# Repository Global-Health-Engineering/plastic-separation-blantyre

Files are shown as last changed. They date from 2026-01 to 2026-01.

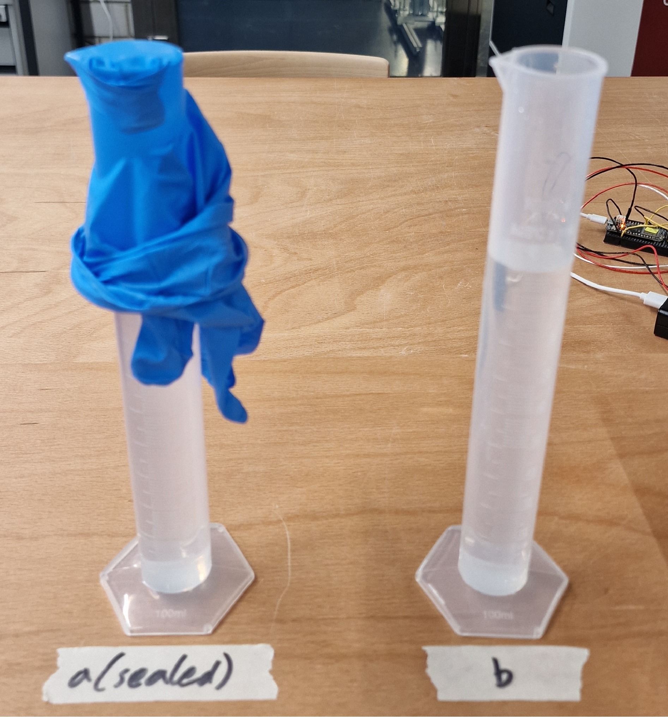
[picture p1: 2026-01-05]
media/testing/04-light_sink_float_sep-proof_of_concept/evaporation_test2.jpg

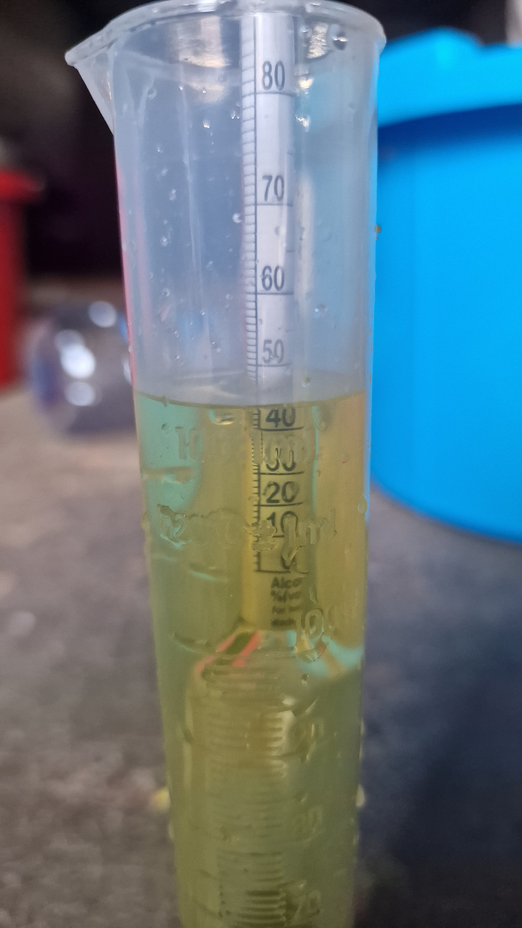
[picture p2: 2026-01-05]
media/testing/07-sink_float_prototype_test/ethanol_water_measurement-post_separation.jpg

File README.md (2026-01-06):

<!-- badges: start -->


<!-- badges: end -->

<h1> Plastic Separator - Design and Results </h1>

<b>Contributors</b>  
- Sven Prinz <a href="https://orcid.org/0009-0000-4485-1235">
ORCID logo 0009-0000-4485-1235
</a>, <a href="sprinz@ethz.ch">sprinz@ethz.ch</a> *author, maintainer*  
- Jakub Tkaczuk <a href="https://orcid.org/0000-0001-7997-9423">
ORCID logo 0000-0001-7997-9423
</a> *supervisor*  
- Elizabeth Tilley <a href="https://orcid.org/0000-0002-2095-9724">
ORCID logo 0000-0002-2095-9724
</a> *supervisor*  

<br>
<p align="middle"> 

<br><br>
It compliments the openly-accessible master’s thesis, available on the<br \>  
<a href="http://hdl.handle.net/20.500.11850/791439">ETH Research Collection</a>.
</p>

<b>Date of Thesis</b>  
- 2025-05-28 until 2025-12-19

<b>Locations</b>  
- Zurich, Switzerland
- Blantyre, Malawi

# Thesis Abstract

The growing thread of plastic waste is visible all over the world. Production and consumption increase each year, while the rate of recycling lags behind significantly, heightening the burden on health and the environment.
Efforts are being made to counteract this development, with mixed outcomes.
In collaboration with *ArtMal* and *WASTE Advisers*, two NGOs active in Blantyre, Malawi, it is aimed to return discarded plastic waste to the recycling process.
After failed attempts to reuse the plastic in form of molded bricks due to property differences between various types, a large quantity of mixed plastic flakes remains.
The goal of this thesis is to divide the mixed flakes by their type and, thus, reintroduce them into the ongoing recycling efforts in Malawi.

The thesis is structured in two parts.
During the first period, a literature review including small scale testing was conducted to evaluate the feasibility of various plastic separation methods.
The following field work in Malawi consisted of the plastic waste assessment, the design and manufacturing of a suitable separation prototype, and the validation of its functionality.

It was found that the most promising method for the setting in Blantyre is the sink-float method due to its simplicity and robustness.
The resulting prototype is a manually operated two-stage sink-float separator which addresses the sorting of PP, HDPE, and PET.
Due to its fabrication out of locally available material, a cost-efficient and reproducible design was obtained.
With this prototype, separation purities of 96.55 % for PET and 99.77 % for HDPE were achieved, allowing their reuse in recycling operations by *ArtMal* and *WASTE Advisers*. The purity of PP remained insufficient at 69.76 %.

However, the resulting recyclates are not of satisfying quality for all uses due to a mix of colors as well as a small amounts of PVC and other contaminants remaining in the product.
Especially for contaminated flakes, a supplementary washing solution is necessary.
Additionally, one aspect that this prototype has in common with other separation methods is the need for affordable (in-line) quality verification of the recyclate.
By addressing these complementary systems such as the washing, contaminant removal, and quality control in future work, the prototype's deployment beyond the flakes stored by *WASTE Advisers* becomes viable.

# Repository Overview

To supplement the thesis and allow reproduction of the prototype design and results, all developed resources are published in this repository.
The repository has the following directory tree:

    .
    ├── analysis
    ├── data
    │   ├── derived_data
    │   └── raw_data
    ├── hardware
    │   ├── design
    |   |   ├── S_separation
    |   |   |   └── vacuum_mellerware
    |   |   └── W_washing
    │   └── testing
    └── media
        ├── design
        ├── manufacturing
        └── testing
            ├── 01-sink_float_sep-proof_of_concept
            ├── 02-hdp_sep-proof_of_concept
            ├── 03-ldp_sep-proof_of_concept
            ├── 04-light_sink_float_sep-proof_of_concept
            ├── 05-water_quality_test
            ├── 06-plastic_waste_analysis
            └── 07-sink_float_prototype_test
Each main directory contains its own `README.md` file describing the content in more detail.

| Main directory | Content |
|---|---|
| `./analysis` | Code for data analysis |
| `./data` | Data generated during the project |
| `./hardware` | Prototype design, and testing documentation |
| `./media` | Photos and videos concerning the project |

# License

The complete design and available materials are licensed under [Creative Commons Attribution 4.0 International](https://github.com/Global-Health-Engineering/plastic-separation-blantyre/blob/main/LICENSE.md).

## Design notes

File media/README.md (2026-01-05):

---
README for `./media`
---

In the `./media` directory, photos and videos concerning the project are stored.
It is divided into three sub-directories: `design`, `manufacturing`, and `testing`.

**Note:** Not all media files (especially videos) are available on GitHub. Request access to supplementary material from the author.

# `media/design`

This directory contains screenshots of the prototype unit representations in the CAD software Siemens NX 1988.
The underlying part files are available in the `./hardware/design` directory.

Furthermore, the projected workflow of the washing and separation process is visualized in a video.

# `media/manufacturing`

Here, the fabrication process and milestones of the prototype manufacturing are documented.

# `media/testing`

In this directory, the media recorded during the tests is provided.
It is sorted into one folder for each conducted test and named correspondingly.
For detailed information on the different tests, see the `README.md` file in the `./hardware/testing` directory.

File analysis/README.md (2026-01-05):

---
README for `./analysis`
---

This folder contains the R script `separation_result_derivation.R` to extract, clean, and format the test results acquired from RTT's flakeanalyser.
It reads the excel sheet obtained from the flakeanalyser for each measured sample `07-sink_float_prototype_test-sample_X.xlsx` (with X = 1...5) in the directory `./analysis/data/raw_data`. After the processing, each result (two files per sample) is saved to `./analysis/data/derived_data` named `07-sink_float_prototype_test-sample_X-separation.csv` and `07-sink_float_prototype_test-sample_X-grain_size.csv` as CSV files.

| Input | Directory |
| --- | --- |
| `07-sink_float_prototype_test-sample_1.xlsx` | `./analysis/data/raw_data` |
| `07-sink_float_prototype_test-sample_2.xlsx` | `./analysis/data/raw_data` |
| `07-sink_float_prototype_test-sample_3.xlsx` | `./analysis/data/raw_data` |
| `07-sink_float_prototype_test-sample_4.xlsx` | `./analysis/data/raw_data` |
| `07-sink_float_prototype_test-sample_5.xlsx` | `./analysis/data/raw_data` |

| Output | Directory |
| --- | --- |
| `07-sink_float_prototype_test-sample_1-separation.csv` | `./analysis/data/derived_data` |
| `07-sink_float_prototype_test-sample_1-grain_size.csv` | `./analysis/data/derived_data` |
| `07-sink_float_prototype_test-sample_2-separation.csv` | `./analysis/data/derived_data` |
| `07-sink_float_prototype_test-sample_2-grain_size.csv` | `./analysis/data/derived_data` |
| `07-sink_float_prototype_test-sample_3-separation.csv` | `./analysis/data/derived_data` |
| `07-sink_float_prototype_test-sample_3-grain_size.csv` | `./analysis/data/derived_data` |
| `07-sink_float_prototype_test-sample_4-separation.csv` | `./analysis/data/derived_data` |
| `07-sink_float_prototype_test-sample_4-grain_size.csv` | `./analysis/data/derived_data` |
| `07-sink_float_prototype_test-sample_5-separation.csv` | `./analysis/data/derived_data` |
| `07-sink_float_prototype_test-sample_5-grain_size.csv` | `./analysis/data/derived_data` |

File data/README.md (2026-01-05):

---
README for `./data`
---

The `./data` directory contains two sub-directories: `raw_data` and `derived_data`.

# `data/raw_data`

This directory contains unedited raw data. The data was obtained from tests conducted during the course of the master thesis.
The procedures with which the results were obtained are documented for each test in the testing documents in the`./hardware/testing` directory.

Files are stored in Microsoft excel worksheets (xlsx) files.

| Filename | Date of data collection | Geographic location of data collection |
| --- | --- | --- |
| `01_sink_float_sep-proof_of_concept-results.xlsx` | 2025-06-15 | ETH CLA, Tannenstrasse 3, 8092 Zurich, Switzerland |
| `02-hdp_sep-proof_of_concept-results.xlsx` | 2025-06-18 | ETH CLA, Tannenstrasse 3, 8092 Zurich, Switzerland |
| `03-ldp_sep-proof_of_concept-results.xlsx` | 2025-06-19 | ETH CLA, Tannenstrasse 3, 8092 Zurich, Switzerland |
| `04-light_sink_float_sep-proof_of_concept-results.xlsx` | 2025-07-04 - 2025-07-07 | ETH CLA, Tannenstrasse 3, 8092 Zurich, Switzerland |
| `07-sink_float_prototype_test-sample_1.xlsx` | 2025-09-24 (Sampling) | WASTE Advisers Innovation Hub, Chigumula, Malawi (15°53'08.5"S 35°03'49.5"E) |
| `07-sink_float_prototype_test-sample_2.xlsx` | 2025-09-24 (Sampling) | WASTE Advisers Innovation Hub, Chigumula, Malawi (15°53'08.5"S 35°03'49.5"E) |
| `07-sink_float_prototype_test-sample_3.xlsx` | 2025-09-24 (Sampling) | WASTE Advisers Innovation Hub, Chigumula, Malawi (15°53'08.5"S 35°03'49.5"E) |
| `07-sink_float_prototype_test-sample_4.xlsx` | 2025-09-24 (Sampling) | WASTE Advisers Innovation Hub, Chigumula, Malawi (15°53'08.5"S 35°03'49.5"E) |
| `07-sink_float_prototype_test-sample_4.xlsx` | 2025-09-24 (Sampling) | WASTE Advisers Innovation Hub, Chigumula, Malawi (15°53'08.5"S 35°03'49.5"E) |

For further information see the `README.md` file in the `./data/raw_data` directory.

# `data/derived_data`

This directory contains data that has been cleaned, processed, and formatted using the data in the `./data/raw_data` directory.
Files, where only trivial analysis steps were applied, are stored in xlsx format with the calculations implemented in the worksheet.
For the cases, where a (little) more comprehensive processing was needed, the files are stored in comma-separated values (CSV) files.

For further information see the `README.md` file in the `./data/derived_data` directory.

# File list

| directory | filename | description |
| --- | --- | --- |
| `./data/raw_data` | `01_sink_float_sep-proof_of_concept-results.xlsx` | Raw result data recorded during test 01 "Sink-float separation - Proof of concept" |
| `./data/raw_data` | `02-hdp_sep-proof_of_concept-results.xlsx` | Raw result data recorded during test 02 "HDP separation - Proof of concept" |
| `./data/raw_data` | `03-ldp_sep-proof_of_concept-results.xlsx` | Raw result data recorded during test 03 "LDP separation - Proof of concept" |
| `./data/raw_data` | `04-light_sink_float_sep-proof_of_concept-results.xlsx` | Raw result data recorded during test 04 "Light sink-float separation - Proof of concept" |
| `./data/raw_data` | `07-sink_float_prototype_test-sample_1.xlsx` | Raw result data of sample 1 from the prototype tests analyzed by the flakeanalyser from RTT |
| `./data/raw_data` | `07-sink_float_prototype_test-sample_2.xlsx` | Raw result data of sample 2 from the prototype tests analyzed by the flakeanalyser from RTT |
| `./data/raw_data` | `07-sink_float_prototype_test-sample_3.xlsx` | Raw result data of sample 3 from the prototype tests analyzed by the flakeanalyser from RTT |
| `./data/raw_data` | `07-sink_float_prototype_test-sample_4.xlsx` | Raw result data of sample 4 from the prototype tests analyzed by the flakeanalyser from RTT |
| `./data/raw_data` | `07-sink_float_prototype_test-sample_4.xlsx` | Raw result data of sample 5 from the prototype tests analyzed by the flakeanalyser from RTT |
| `./data/raw_data` | `README.md` | Information regarding the files in the directory including a description of parameters used |
| `./data/derived_data` | `01_sink_float_sep-proof_of_concept-evaluations.xlsx` | Processed result data of test 01 "Sink-float separation - Proof of concept" |
| `./data/derived_data` | `02-hdp_sep-proof_of_concept-evaluations.xlsx` | Processed result data of test 02 "HDP separation - Proof of concept" |
| `./data/derived_data` | `03-ldp_sep-proof_of_concept-evaluations.xlsx` | Processed result data of test 03 "LDP separation - Proof of concept" |
| `./data/derived_data` | `04-light_sink_float_sep-proof_of_concept-evaluations.xlsx` | Processed result data of test 04 "Light sink-float separation - Proof of concept" |
| `./data/derived_data` | `07-sink_float_prototype_test-sample_1-grain_size.csv` | Processed material composition results of sample 1 from the prototype tests analyzed by the flakeanalyser from RTT |
| `./data/derived_data` | `07-sink_float_prototype_test-sample_1-separation.csv` | Processed grain size composition results of sample 1 from the prototype tests analyzed by the flakeanalyser from RTT |
| `./data/derived_data` | `07-sink_float_prototype_test-sample_2-grain_size.csv` | Processed material composition results of sample 2 from the prototype tests analyzed by the flakeanalyser from RTT |
| `./data/derived_data` | `07-sink_float_prototype_test-sample_2-separation.csv` | Processed grain size composition results of sample 2 from the prototype tests analyzed by the flakeanalyser from RTT |
| `./data/derived_data` | `07-sink_float_prototype_test-sample_3-grain_size.csv` | Processed material composition results of sample 3 from the prototype tests analyzed by the flakeanalyser from RTT |
| `./data/derived_data` | `07-sink_float_prototype_test-sample_3-separation.csv` | Processed grain size composition results of sample 3 from the prototype tests analyzed by the flakeanalyser from RTT |
| `./data/derived_data` | `07-sink_float_prototype_test-sample_4-grain_size.csv` | Processed material composition results of sample 4 from the prototype tests analyzed by the flakeanalyser from RTT |
| `./data/derived_data` | `07-sink_float_prototype_test-sample_4-separation.csv` | Processed grain size composition results of sample 4 from the prototype tests analyzed by the flakeanalyser from RTT |
| `./data/derived_data` | `07-sink_float_prototype_test-sample_5-grain_size.csv` | Processed material composition results of sample 5 from the prototype tests analyzed by the flakeanalyser from RTT |
| `./data/derived_data` | `07-sink_float_prototype_test-sample_5-separation.csv` | Processed grain size composition results of sample 5 from the prototype tests analyzed by the flakeanalyser from RTT |
| `./data/derived_data` | `README.md` | Information regarding the files in the directory including a description of parameters used |

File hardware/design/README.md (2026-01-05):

---
README for `./hardware/design`
---

This directory contains the design files for the developed prototype.
The parts were designed using the CAD software **NX 1988** from Siemens.

The higher level assembly of the design `A_full_process_line.prt` consists of the two prototype units designed in the course of this thesis - the air classifier and the sink-float separator - and the washing drum built by *Laios (2025)*.
The folder `S_separation` contains both assembly files and their subordinate part files (provided as PRT and STP files), as well as the technical drawings of the parts (provided as PRT and PDF files) of the two separation prototype units.
Additionally, the folder `vacuum_mellerware` in the `./hardware/design/S_separation` directory contains pictures in PNG format that represent the vacuum cleaner used in the assembly of the air classifier design.
The vacuum cleaner depicted in the figures is the <a href="http://www.mellerware.co.za/products/mellerware-vacuum-cleaner-bagless-cyclone-plastic-red-1.2l-1200w-innovac/31120A">Bagless Cyclone Vacuum Cleaner "Innovac"</a> by Mellerware.
The directory `./hardware/design/W_washing` contains a digital version of *Laois*' washing drum prototype for representation purposes. Its assembly is only available as  Siemens PRT file, while the individual parts are also available as STP files.

Apart from the CAD files, `HDPE_sheet_utilization.pdf` in `./hardware/design` offers the area utilization of the HDPE sheets used during production of the prototype. The initial HDPE sheets were manufactured by ArtMal in Blantyre, Malawi.

**Reference:**
*Laios, T. (2025). Plastic for Recycling Cleaning [Unpublished master thesis]. ETH Zurich.*

# Used naming and color coventions

**File naming convention**

Each designed prototype part file (and its corresponding drawing files) follow the same naming scheme: P_UU_T_NN_PARTNAME.FILEEXTENSION

| Placeholder | Description | Possible values |
| --- | --- | --- |
| P | Abbreviation of process | W (washing), S (separation) |
| UU | Abbreviation of prototype unit | AC (Air classifier), SF (Sink-float separator), WS (Washer drum) |
| T | Abbreviation of NX file type | A (Assembly), M (Model) |
| NN | Identification number of part (unique within a prototype unit) | Natural number incrementing in order of file creation |
| PARTNAME | Name of part/assembly | Any character allowed in file names |
| FILEEXTENSION | Extension of file type | prt (Siemens NX part file/drawing file), stp (step file), pdf (technical drawing exported as PDF) |

**Color codes used in Siemens NX 1988:**
| Material | Color | Translucency setting |
| --- | --- | --- |
| HDPE sheets | Ash Gray | 0% |
| Perforated steel sheets | Granite Gray | 50% |
| PVC pipe | Medium Khaki | 0% |
| Rubber seals | Dark Gray | 0% |
| Steel frame/sheets | Medium Steel | 0% |
| Tubes | Deep Stone | 0% |
| Wood | Medium Umber | 0% |

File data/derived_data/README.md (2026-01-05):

---
README for `./data/derived_data`
---

This folder contains derived data obtained from the tests. The raw data is located in the directory `./data/raw_data`.

The first four evaluation files are obtained from small-scale proof-of-concept tests conducted in the lab:
- `01_sink_float_sep-proof_of_concept-evaluations.xlsx`
- `02-hdp_sep-proof_of_concept-evaluations.xlsx`
- `03-ldp_sep-proof_of_concept-evaluations.xlsx`
- `04-light_sink_float_sep-proof_of_concept-evaluations.xlsx`

As the calculations are trivial, they are directly performed in the excel sheet using the following formulas:
- purity_float = mass(float right) / mass(float total)
- purity_sink = mass(sink right) / mass(sink total)
- combined_purity = 0.5*(purity_float + purity_sink)

These evaluation sheets have an individual structure due to varying tested parameters. Thus, the specific data dictionary is presented in the "general_info" sheet of each file.

The five files `07-sink_float_prototype_test-sample_X-separation.csv` and the five files `07-sink_float_prototype_test-sample_X-grain_size.csv` (with X = 1...5) are generated using the `separation_result_derivation.R` script in the `./analysis` directory. For further information on the processing, see the `README.md` and the R script in the `./analysis` directory.
The results' structure is identical and the data dictionary for the two file classes are explained here:

**Data dictionary - 'separation' files:**
| Variable | Description | Unit |
| --- | --- | --- |
| material | Different material types of analysis | - |
| mass_percent | Mass fraction of that material in the sample | % |
| volume_percent | Volume fraction of that material in the sample | % |
| object_count | Absolute number of detected flakes for that material | - |

**Data dictionary - 'grain_size' files:**
| Variable | Description | Unit |
| --- | --- | --- |
| gain_size | Grain size ranges returned by flakeanalyser | mm |
| area_mm2 | Area fraction of that material in the sample | mm^2 |
| area_percent | Volume fraction of that material in the sample | % |

For more information see the `README.md` file in the `./data` directory.

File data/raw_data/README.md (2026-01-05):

---
README for `./data/raw_data`
---

This folder contains raw data obtained from the tests.

The first four result files are obtained from small-scale proof-of-concept tests conducted in the lab:
- `01_sink_float_sep-proof_of_concept-results.xlsx`
- `02-hdp_sep-proof_of_concept-results.xlsx`
- `03-ldp_sep-proof_of_concept-results.xlsx`
- `04-light_sink_float_sep-proof_of_concept-results.xlsx`

They have an individual structure due to varying tested parameters. Thus, the specific data dictionary is presented in the "general_info" sheet of each file.

The five files `07-sink_float_prototype_test-sample_X.xlsx` (with X = 1...5) are the results of the flakeanalyser from RTT which was used to determine the composition of the prototype samples. Their structure is identical and the most important parameters on the first sheet are explained here:

| Column name | Description |
| --- | --- |
| Material | Material which the flakeanalyser can distinguish |
| Objektanzahl | Absolute number of detected flakes for that material |
| Anzahl Objekte [%] | Relative number of detected flakes for that material |
| Fläche [mm²] | Absolute area measured for that material |
| Fläche [%] | Area fraction of that material in the sample |
| Volumen [mm³] | Absolute volume measured for that material |
| Volumenverteilung [%] | Volume fraction of that material in the sample |
| Gewicht [g] | Derived mass of that material based on measured volume and a total mass of the sample * |
| Gewichtsverteilung [%] | Mass fraction of that material in the sample |

\* The total mass of the sample can not be measured by the machine. Instead, an arbitrary value (123 g) was entered prior to the analysis.

For more information see the `README.md` file in the `./data` directory.

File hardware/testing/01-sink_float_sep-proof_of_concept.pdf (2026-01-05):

June 2025 | 1 of 13

## Sink-float separation - Proof of concept

Testing Document

Version 1

Date:

- Start: 06.06.2025
- End: 16.06.2025

Contents

### General description and purpose

Purpose of test

During an in-depth review of literature on plastic waste separation processes, the sink-float separation process emerged as the most promising in the setting of Blantyre. For most research toward plastic separation, the difficulty to translate the findings to real applications was criticized, since oftentimes virgin plastics are used which could vary drastically from post-consumer plastic waste in material properties and behavior (Wang et al., 2015). To validate the expected material behavior and to find the most suitable separation approach during the sink-float separation process, a proof-of-concept test series is conducted. These findings are then used to evaluate further separation steps.

Description of Test

For the test, the most common plastic waste types are used: PP, LDPE, HDPE, PS, PET, PVC. To allow for simple analysis of the results, all plastic types are color coded (plastic waste of different colors is used). For each item, the plastic type is validated by a handheld NIR spectrometer (MicroPHAZIR PC) (https://www.physitek.fr/en/produit/microphazir-pc-handheld-nir-spectrometer/) and recorded together with its color. Additionally, the item’s mass is recorded. Each item should weigh at least 60g. Alternatively, multiple identical items can be used for a single plastic type. Then, all items are separately crushed into plastic flakes using the HoliShred V1. (https://holimaker.fr/modules-accessoires-et-materiaux/) These flakes will be smaller than the ones stored in Blantyre, but according to research, larger flakes show better wettability (Pita & Castilho, 2017). Therefore, if it works in the lab with small flakes, it is expected to be transferable to the plastic waste in Blantyre. The resulting flakes are checked for purity and then weighted again.

For the tests, multiple batches of a mixture of the different plastic types are created. For each batch, 5 g of each plastic type are added to a container creating test batches of 30 g of mixed plastic waste. Twelve different proof-of-concept tests are run in small glasses or other transparent containers to which one of the plastic test batches is added, investigating differences in the separation processes after five minutes:

a1. tap water
a2. tap water, constant slow stirring (5 min)
a3. tap water, vigorous stirring (3 min), let settle (2 min)
b1. tap water, detergent (0.5 g per liter)¹
b2. tap water, detergent (0.5 g per liter), constant slow stirring (5 min)
b3. tap water, detergent (0.5 g per liter), vigorous stirring (3 min), let settle (2 min)
c1. tap water, CaCl2 (Calcium chloride, 1 g per liter)²
c2. tap water, CaCl2 (Calcium chloride, 1 g per liter), constant slow stirring (5 min)
c3. tap water, CaCl2 (Calcium chloride, 1 g per liter), vigorous stirring (3 min), let settle (2 min) d1. tap water, NaCl (Sodium chloride, 0.4 g per liter) as an alternative to CaCl2
d2. tap water, NaCl (Sodium chloride, 0.4 g per liter), constant slow stirring (5 min)
d3. tap water, NaCl (Sodium chloride, 0.4 g per liter), vigorous stirring (3 min), let settle (2 min)

1 Detergents / soap reduce the surface tension of water which should improve the wettability of hydrophobic plastic flakes. 2 The addition of CaCl2 has shown to increase the wettability of plastics (Pongstabodee et al., 2008).

Lastly, the results are evaluated: first, visually to see how well the separation of the colors has occurred, and then by measuring the two resulting fractions’ total mass as well as the masses of the correctly and incorrectly assigned plastics. This allows to calculate the mass percentage / purity of the resulting fractions.

The expected / desired outcome is a clear separation between the low-density polymers (LDP) – PP, LDPE, HDPE – and the high-density polymers (HDP) – PS, PET, PVC.

Calculations

Separation medium concentration for salts CaCl2 Dihydrate (M = 147.01 g
mol

,

1g
l

) and NaCl (M =
58.44 g
mol

):

C(CaCl2 ∗ 2H20) =

n
V

=

m(CaCl2∗2H20)
M(CaCl2∗2H20)∗V(solution)

=

1g
147.01 g
mol ∗1l

≈ 0.007 mol
l

C(CaCl2 ∗ 2H20) = C(NaCl)

=> solution in 0.9 l water:
m(CaCl2 ∗ 2H20) = 0.9g

m(NaCl) = C(NaCl) ∗ M(NaCl) ∗ V(solution) =

m(CaCl2∗2H20)
M(CaCl2∗2H20)

∗ M(NaCl) ≈ 0.4g

Plastic separation results:

Purity φfloat: | φfloat = mfloatLDP/mfloat
Recovery Rfloat: | Rfloat = mfloatLDP/minLDP
Purity φsink: | φsink = msinkHDP/msink
Recovery Rsink: | Rsink = msinkHDP/minHDP
Purity φcombined: | φcombined = (φsink + φfloat)/2

Schedule of test with all steps required

1. Acquire plastic waste of types PP, LDPE, HDPE, PS, PET, PVC in different colors.
2. For each item, scan the material with the NIR spectrometer and record its color and mass. (Each item should weigh at least 60g. Alternatively, multiple identical items can be used.)
3. Clean the HoliShred V1 of any remainders of old plastic. (DO NOT PUT HAND IN SHREDDER WHEN MOTOR IS PLUGGED IN!)
4. For each item, shred the item and collect the flakes in a separate container.
5. Record the resulting mass of flakes for each shredded item.
6. Prepare 3 batches of mixed test plastics which consists of 5 g of each plastic type (30 g total per batch).
7. Prepare 3 transparent containers as testing environments for test sequence a1 – a3 with

a1. | 300 ml of tap water
a2. | 300 ml of tap water, magnetic stir bar, place on magnetic mixer
a3. | 300 ml of tap water, magnetic stir bar, place on magnetic mixer
8. Set up camera to record the separation behavior over the test timeframe and start recording.
9. Add mixed test plastic batches to test containers and place the strainer on top. Start the mixer for batch a2 at 300 rpm, and a3 at 600 rpm, and start a timer of 5 minutes.
10. After 3 minutes, stop mixer of a3.
11. When the 5-minute timer is done, stop the mixer of a2.
12. For each batch separately, remove the floating fraction of the plastics of each container by skimming with a strainer, (for b1 – d3) rinse the flakes in the strainer with fresh water, and place them on a paper towel to dry.
13. For each batch separately, pour the rest of the container through the strainer over a sink to extract the sinking fraction of the plastics, (for b1 – d3) rinse the flakes in the strainer with fresh water, and place them on a paper towel to dry.
14. After the flakes have fully dried, record the total mass for each fraction in each batch.
15. Sort each fraction in each batch into LDP and HDP (using the color coding) and record the masses for each plastic type.
16. Calculate the recovery and purity for each of the 6 batches.
17. For each batch separately, mix the fractions to obtain the mix of plastic types of 30 g from
step 6.
18. Repeat steps 7-16 once more to investigate changes in the process after wetting and drying the plastic flakes once.
19. Repeat steps 6-16 for the test sequences b1 – b3, c1 – c3, and d1 – d3. (This can be done in parallel, while the previous test sequence plastic is drying.) Prepare one batch of 1.5 l of each solution before distributing it to the three containers to reduce deviation.
b1. | 300 ml of tap water, 0.15 g of detergent
b2. | 300 ml of tap water, 0.15 g of detergent, magnetic stir bar, place on magnetic mixer
b3. | 300 ml of tap water, 0.15 g of detergent, magnetic stir bar, place on magnetic mixer
c1. | 300 ml of tap water, 0.3 g of CaCl2
c2. | 300 ml of tap water, 0.3 g of CaCl2, magnetic stir bar, place on magnetic mixer
c3. | 300 ml of tap water, 0.3 g of CaCl2, magnetic stir bar, place on magnetic mixer
d1. | 300 ml of tap water, 0.1 g of NaCl
d2. | 300 ml of tap water, 0.1 g of NaCl, magnetic stir bar, place on magnetic mixer
d3. | 300 ml of tap water, 0.1 g of NaCl, magnetic stir bar, place on magnetic mixer

Risk analysis

Potential risks associated with this test

Shredding: Possible threat for hands (sharp blades) and eyes (plastic flakes flying off the shredder).

Intense stirring: Risk for plastic flakes or drops of the solution to get into the eyes or spilling.

CaCl2: The usage of solid CaCl2 poses risks to eyes and skin due to its strong hygroscopic properties, possibly leading to irritation or burns, if in contact with the solid salt (“Calcium Chloride,” 2025).

Mitigation steps

Shredding: Safety glasses are worn during the whole shredding process. A rod is used if physical intervention with the shredder is necessary, never the hands.

Intense stirring: Safety glasses are worn during the experiments. Paper towels are prepared for the event of spills.

CaCl2: Safety glasses and chemically resistant gloves are worn during the handling of the salt (s). The CaCl2 container is only opened when preparing the solution and closed immediately afterwards.

Risks after taking mitigation steps

Shredding / Intense stirring: None.

CaCl2: None, CaCl2 is non-toxic when dissolved in water in small quantities (“Calcium Chloride,” 2025).

### Tools and devices required

Tool | Check-in tick
1x safety glasses | X
1x pair of chemically resistant gloves | X
1x rod (wood or plastic) | X
Paper towels | X
1x laptop | X
1x camera (phone) | X
1x timer (laptop or phone can be used) | X
1x MicroPHAZIR PC (https://www.physitek.fr/en/produit/microphazir-pc-handheld-nir-spectrometer/) | X
1x HoliShred V1 (https://holimaker.fr/modules-accessoires-et-materiaux/) | X
1x scale | X
6x container for different plastic types | X
3x container for mixed plastic test batches | X
3x transparent container for tests | X
1x large container (capacity >= 1 l) | X
Plastic waste, 60 g each (PP, LDPE, HDPE, PS, PET, PVC) in different colors | X (insufficient)
2x magnetic stir bar | X (one)

2x magnetic mixer | X (one)
3x strainer | X (two)
3.6 l tap water | X
0.45 g dish soap or other detergent | X
0.9 g CaCl2 | X
0.4 g NaCl | X
1x tweezers | X
1x calculator | X

### Testing Results

All recordings of the separation process and pictures of the results are available here. (https://drive.google.com/drive/folders/167mom1ztyUyThPXdFDw2byKsVDBJiDWL?usp=drive_link)

Test waste creation

Shredder clogged with PET. Therefore, scissors and wire cutters were used instead to cut flakes. → varying flake sizes, more similar to Blantyre waste

The resulting plastic flakes are depicted in Figure 1.

Since not for every plastic type enough material could be found, the mixed plastic test badge does not consist of 5 g each. Instead, a 1/20 of each plastic type is used for a mixed test plastic batch. Furthermore, the cracker packaging (PP) is not used in the test batch as its reflective side makes the visual differentiation difficult.

Waste item | Material (printed) | Material (scanned) | Color | Mass before shredding [g] | Mass after shredding [g]
Water bottle | PET | PET 0.983 | Transparent, clear | 27.6 | 54.1
Water bottle | PET | PET 0.978 | Transparent, green | 17.7
Fruit tray | R-PET | PET 0.976 | Transparent, clear | 18.5
Cookie tray | PET | Unidentified PET 0.302 | Brown | 6.5
Cottage cheese cup | PS | PS 0.993 | White | 4.4 | 48.8
Yoghurt cup small x3 | PS | PS 0.974 | White | 9.6
Yoghurt cup large x4 | PS | PS 0.951 | White | 34.9
Cream cheese lid x2 | PP | PP 0.998 | Dark green, white print | 8.3 | 13.0
Cream cheese lid | PP | PP 0.997 | Dark green, white print | 4.8
Cracker packaging | PP | Unidentified PA 0.340 | Brown-orange, inside silver | 4.6 | 4.5 Not used
Detergent bottle | HDPE | PE 0.994 | Blue | 32.8 | 41.8
Bottle caps x6 | HDPE | PE 0.997 | Red | 9.2
Pipe | / | PVC 0.952 | Gray | 35.1 | 35
Vegetable bag (LDPE?) | / | PE 0.958 | Transparent, red/brown | 5.3 | 5.4

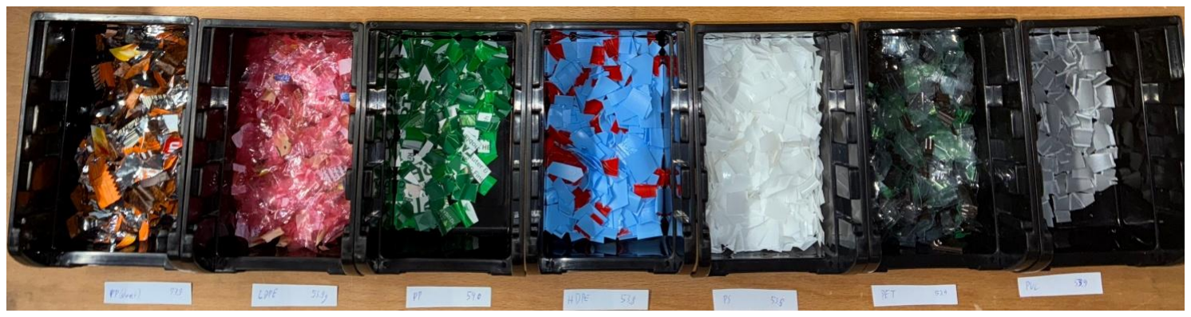
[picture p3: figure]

Figure 1: Prepared plastic flakes before test batch creation.

Separation test

Since only one magnetic stirrer was available, the vigorous stirring batches (a3, b3, c3, d3) were done by hand with a fork handle. The solution plastic mixture was stirred at a high velocity with periodic direction changes to create turbulences in the liquid.

Furthermore, the input mass measurements were done using a scale with an accuracy of 0.1 g. This leads to the difference in the theoretical mass of 9.6 g and the actual total input mass measured.

However, the resulting output masses for the sink and float fractions and their composition was done using a precise laboratory scale (Mettler-Toledo NewClassic MS204/M). (https://www.bayernwaage.de/de/produkte/Analytische_Waagen_Semimikrowaagen_METTLER_TOLEDO_NewClassic_MS_NewClassic_MS204_M_kaufen_101281_11142076.php) This results in representative results for the purity, but not for the recovery values.

Sequence a

Run 1:

Test | Input masses [g] | Float-output masses [g] | Sink-output masses [g]
a1 | | PP 0.6 | LDPE 0.2 | HDPE 2.0 | PP 0.52 | LDPE 0.12 | HDPE 1.90 | PP 0 | LDPE 0 | HDPE 0
| | PS 2.4 | PET 2.7 | PVC 1.7 | PS 1.43 | PET 1.09 | PVC 0.35 | PS 0.93 | PET 1.50 | PVC 1.27

Tot: 9.2 (theoretically 9.6)

a2 | | PP 0.6 | LDPE 0.2 | HDPE 2.0 | | | 2.72 | PP 0 | LDPE 0.01 | HDPE 0
PS 2.4 | PET 2.7 | PVC 1.7 | | | PS 0.12 | PET 0.03 | PVC 0 | 6.58

Tot: 9.4 (theoretically 9.6)

PP | LDPE | HDPE
PS | PET | PVC
a3 | PP 0.6 | LDPE 0.2 | HDPE 2.0 | 2.59 | | | PP 0 | LDPE 0.003 | HDPE 0
| PS 2.4 | PET 2.7 | PVC 1.7 | PS 0.19 | PET 0 | PVC 0 | 6.39

Tot: 9.2 (theoretically 9.6)

PP | LDPE | HDPE
PS | PET | PVC

Run 2:

Test | Input masses [g] | Float-output masses [g] | Sink-output masses [g]
a1 | | PP 0.6 | LDPE 0.2 | HDPE 2.0 | PP 0.52 | LDPE 0.23 | HDPE 2.00 | PP 0 | LDPE 0.004 | HDPE 0
| | PS 2.4 | PET 2.7 | PVC 1.7 | PS 1.17 | PET 0.96 | PVC 0.10 | PS 1.19 | PET 1.61 | PVC 1.52

Tot: 9.2 (theoretically 9.6)

a2 | PP 0.6 | LDPE 0.2 | HDPE 2.0 | 2.63 | | | PP 0 | LDPE 0.01 | HDPE 0
| PS 2.4 | PET 2.7 | PVC 1.7 | PS 0.21 | PET 0.07 | PVC 0 | 6.45

Tot: 9.4 (theoretically 9.6)

PP | LDPE | HDPE
PS | PET | PVC
a3 | | PP 0.6 | LDPE 0.2 | HDPE 2.0 | | | 2.63 | PP 0 | LDPE 0.001 | HDPE 0
PS 2.4 | PET 2.7 | PVC 1.7 | | | PS 0.27 | PET 0.01 | PVC 0 | 6.28

Tot: 9.2 (theoretically 9.6)

PP | LDPE | HDPE
PS | PET | PVC

Any unexpected behaviors (clustering, foam formation, intermediate layers):

- a1 run 1: high purity, bad recovery (only what touches water)
- a1 run 1 (also other sequences for test 1): some material sinks as soon as the strainer touches the floating fraction when extracting

Sequence b

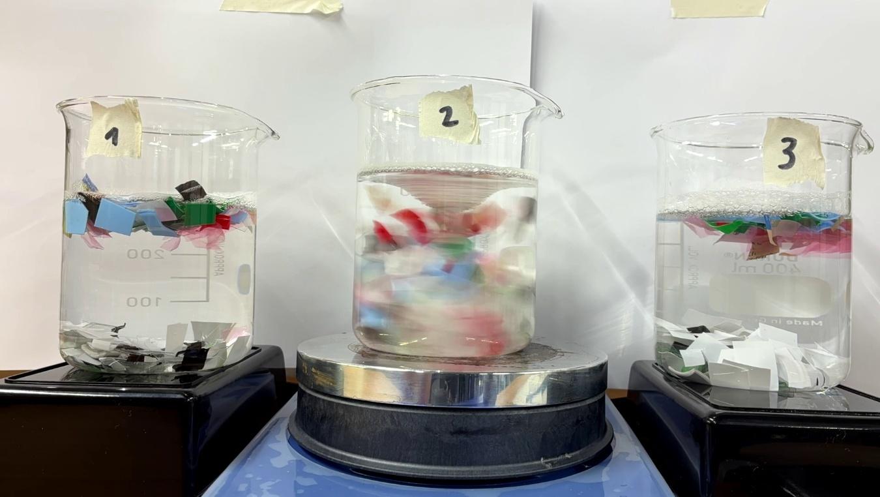
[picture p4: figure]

Figure 2: Separation setup for test sequence b.

Test | Input masses [g] | Float-output masses [g] | Sink-output masses [g]
b1 | | PP 0.6 | LDPE 0.2 | HDPE 2.0 | 3.36 | | | PP 0 | LDPE 0.0001 | HDPE 0
| | PS 2.4 | PET 2.7 | PVC 1.7 | PS 0.54 | PET 0.21 | PVC 0 | 5.88

Tot: 10.0 (theoretically 9.6)

PP | LDPE | HDPE
PS | PET | PVC
b2 | | PP 0.6 | LDPE 0.2 | HDPE 2.0 | | | 2.91 | PP 0 | LDPE 0.01 | HDPE 0
PS 2.4 | PET 2.7 | PVC 1.7 | | | PS 0.0001 | PET 0 | PVC 0 | 6.43

Tot: 9.4 (theoretically 9.6)

PP | LDPE | HDPE
PS | PET | PVC
b3 | PP 0.6 | LDPE 0.2 | HDPE 2.0 | 2.61 | | | PP 0 | LDPE 0.003 | HDPE 0
| PS 2.4 | PET 2.7 | PVC 1.7 | PS 0 | PET 0 | PVC 0 | 6.70

Tot: 9.4 (theoretically 9.6)

PP | LDPE | HDPE
PS | PET | PVC

Any unexpected behaviors (clustering, foam formation, intermediate layers):

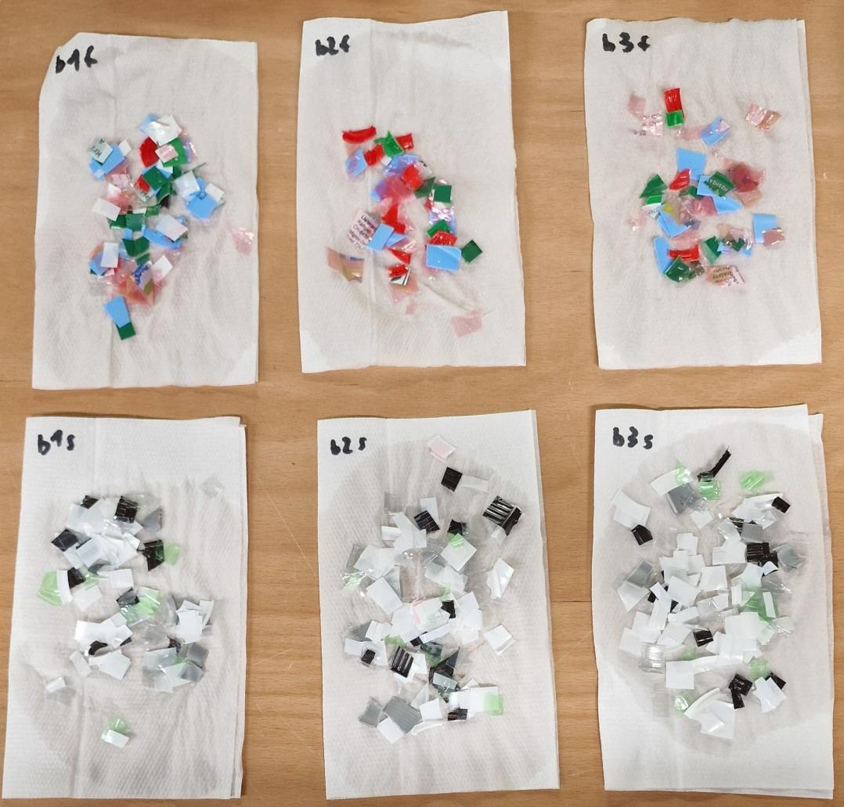
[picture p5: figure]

Figure 3: Resulting fractions of sequence b.

Sequence c

Test | Input masses [g] | Float-output masses [g] | Sink-output masses [g]
c1 | | PP 0.6 | LDPE 0.2 | HDPE 2.0 | 2.64 | | | PP 0 | LDPE 0.0003 | HDPE 0
| | PS 2.4 | PET 2.7 | PVC 1.7 | PS 1.33 | PET 0.72 | PVC 0.19 | 4.37

Tot: 9.3 (theoretically 9.6)

PP | LDPE | HDPE
PS | PET | PVC
c2 | PP 0.6 | LDPE 0.2 | HDPE 2.0 | 3.30 | | | PP 0 | LDPE 0 | HDPE 0
| PS 2.4 | PET 2.7 | PVC 1.7 | PS 0.14 | PET 0.02 | PVC 0 | 6.36

Tot: 9.9 (theoretically 9.6)

PP | LDPE | HDPE
PS | PET | PVC
c3 | PP 0.6 | LDPE 0.2 | HDPE 2.0 | 2.68 | | | PP 0 | LDPE 0.003 | HDPE 0
| PS 2.4 | PET 2.7 | PVC 1.7 | PS 0.11 | PET 0.03 | PVC 0 | 6.54

Tot: 9.3 (theoretically 9.6)

PP | LDPE | HDPE
PS | PET | PVC

Any unexpected behaviors (clustering, foam formation, intermediate layers):

- c2 & c3: some LDPE foil sticks to PS pieces in sink fraction

Sequence d

Test | Input masses [g] | Float-output masses [g] | Sink-output masses [g]
d1 | | PP 0.6 | LDPE 0.2 | HDPE 2.0 | 2.69 | | | PP 0 | LDPE 0 | HDPE 0
| | PS 2.4 | PET 2.7 | PVC 1.7 | PS 1.10 | PET 0.72 | PVC 0 | 4.60

Tot: 9.2 (theoretically 9.6)

PP | LDPE | HDPE
PS | PET | PVC
d2 | PP 0.6 | LDPE 0.2 | HDPE 2.0 | 2.62 | | | PP 0 | LDPE 0 | HDPE 0
| PS 2.4 | PET 2.7 | PVC 1.7 | PS 0.05 | PET 0.08 | PVC 0 | 6.45

Tot: 9.4 (theoretically 9.6)

PP | LDPE | HDPE
PS | PET | PVC
d3 | PP 0.6 | LDPE 0.2 | HDPE 2.0 | 2.79 | | | PP 0 | LDPE 0.01 | HDPE 0
| PS 2.4 | PET 2.7 | PVC 1.7 | PS 0.06 | PET 0 | PVC 0 | 6.41

Tot: 9.3 (theoretically 9.6)

PP | LDPE | HDPE
PS | PET | PVC

Any unexpected behaviors (clustering, foam formation, intermediate layers):

### Evaluation

The calculation of the purity and recovery values are done in MS Excel and saved here. (https://docs.google.com/spreadsheets/d/1295bdl8r2cv-M01rEmeHw8ipx0H08L4w/edit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) The results regarding purity are summarized in Table 1.

Table 1: Purity results sorted by combined purity.

Test | Run | Purity float | Purity sink | Purity combined
b3 | 1 | 100.00% | 99.96% | 99.98%
b2 | 1 | 100.00% | 99.84% | 99.92%
d3 | 1 | 97.89% | 99.84% | 98.87%
c2 | 1 | 95.38% | 100.00% | 97.69%
d2 | 1 | 95.27% | 100.00% | 97.64%
c3 | 1 | 95.04% | 99.95% | 97.49%
a2 | 1 | 94.77% | 99.85% | 97.31%
a3 | 1 | 93.17% | 99.95% | 96.56%
a3 | 2 | 90.38% | 99.98% | 95.18%
a2 | 2 | 90.38% | 99.85% | 95.11%
b1 | 1 | 81.75% | 100.00% | 90.88%
d1 | 1 | 59.65% | 100.00% | 79.82%
a1 | 2 | 55.22% | 99.91% | 77.56%
c1 | 1 | 54.10% | 99.99% | 77.05%
a1 | 1 | 46.95% | 100.00% | 73.48%

All sink fraction results show a high purity of > 99.84 %. The float fractions on the other hand show a large difference in purity, highly dependent on the process. When no stirring is involved in the process, the float fraction purity lies between 46.95 and 81.75 %. When normal tap water is used without the addition of any surfactant with slow or vigorous stirring, the purity of the float fraction lies between 90.38 and 94.77 %. Out of the other processes – slow or vigorous stirring with the addition of surfactants – with a purity range of 95.04 to 100%, the processes involving the use of detergent shows the highest purities. When calculating a combined (averaged) purity of the float and sink fractions for each test, the slow and vigorous stirring of the detergent-water solution are established as the superior processes.

Due to the low accuracy of the scale used for the input plastic mixtures, the calculated recovery values are only of limited use. This is no concern since no rejection fraction is created during this separation process (leading to no unassigned plastic flakes) and, therefore, the purity measurement conveys this information simultaneously.

When comparing run 1 and run 2 of the sequence a, no clear pattern can be observed. This indicates no change of the plastic properties after a cycle of wetting and drying.

In conclusion, a combination of stirring and water treated with detergent as a surfactant are preferable. Next to improving the separation process, the detergent has the added benefit of acting as an additional cleaning step in the plastic waste processing.

The limited accuracy of the test procedure does not allow for a clear advantage of b2 or b3 over the other. This will be used as a degree of freedom in the prototype design.

### Bibliography

Calcium | | chloride. | | (2025). | In | | Wikipedia.

https://en.wikipedia.org/w/index.php?title=Calcium_chloride&oldid=1292953806

Pita, F., & Castilho, A. (2017). Separation of plastics by froth flotation. The role of size, shape and

density | of | the | particles. | Waste | Management, | 60, | 91–99.

https://doi.org/10.1016/j.wasman.2016.07.041

Pongstabodee, S., Kunachitpimol, N., & Damronglerd, S. (2008). Combination of three-stage sink–

float method and selective flotation technique for separation of mixed post-consumer plastic

waste. Waste Management, 28(3), 475–483. https://doi.org/10.1016/j.wasman.2007.03.005

Wang, C., Wang, H., Fu, J., & Liu, Y. (2015). Flotation separation of waste plastics for recycling—

A review. Waste Management, 41, 28–38. https://doi.org/10.1016/j.wasman.2015.03.027

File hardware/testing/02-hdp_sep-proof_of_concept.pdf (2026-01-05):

June 2025 | 1 of 7

## HDP separation - Proof of concept

Testing Document

Version 1

Date:

- Start: 17.06.2025
- End: 18.06.2025

Contents

### General description and purpose

Purpose of test

The findings of test 1 “Sink-float separation - Proof of concept” (https://docs.google.com/document/d/1ngdAf8as1NAp7tlwLvzU2yW88cCANNGC/edit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) have demonstrated the potential of high purities (> 99.9 %) of the two resulting fractions: low-density polymers (LDP) – PP, LDPE, HDPE – and high-density polymers (HDP) – PS, PET, PVC. In the subsequent steps, these fractions must be divided further into its components. This test investigates the next step for the separation of the HDP types, conducted in a similar proof-of-concept fashion (low fidelity, small scale).

Due to the relatively large difference in the density of PS (~ 1.050 g/cm³
) compared to PET and PVC
(~ 1.350 g/cm³

, ~ 1.400 g/cm³
), the extraction of PS from the HDP mixture offers a good starting point (Bearth, 2025). Hereby, three possible methods are considered:
- Swirling:
Adding the HDP mix to water, it will sink to the bottom. When the mixture is then stirred at a very low intensity, the lighter PS is expected to rise while the denser PET and PVC parts stay on the bottom of the container. This allows to skim the PS flakes from the container.
- Pouring:
During test 1, it was observed that the PS flakes exited the container during the pouring process first. If the gap between PS and the other materials is large, this could be utilized for separation.
- Dense sink-float separation:
The density of the separation medium can be increased by adding salt (NaCl) to the water. According to literature, saline water saturated with salt exhibits a density of roughly 1.2 g/cm³ at room temperature (David R. Lide, ed., 2005). As the PS flakes are less dense than the separation medium, they should rise to the surface of the container, while the PET and PVC flakes stay on the bottom.

Description of Test

For this test, the color coded plastic flakes from test 1 are used. One mixed test plastic batch is created from the PS, PET, and PVC flakes. The same masses as in test 1 are used of each material (PS: 2.4 g, PET: 2.7 g, PVC: 1.7 g).

As seen in test 1, no substantial change in the separation behavior is exhibited when rerunning the test on the same plastic. Therefore, the batch is first used to test the swirling and pouring methods. Afterwards, it is used for the dense sink-float separation to avoid the contamination of the other plastic with the salt.

The mixed plastic test batch is added to a transparent container with tap water and stirred by a magnetic mixer so that all plastic flakes collect at the bottom. Then, the RPM of the magnetic mixer is adjusted to reach a point at which the PS flakes are still risen while PET and PVC flakes sink to the bottom. The PS flakes are then skimmed with a strainer and dried. Afterwards, the PET and PVC flakes are removed from the container and dried as well. By visually sorting the correctly and incorrectly separated flakes and measuring the resulting fractions’ masses, the purity of the separation process can be calculated.

For the pouring test, the plastic test batch is added to the water again and wetted so that all flakes sink to the bottom. Then, the flake behavior is inspected during the pouring process into a strainer to see if the observation from test 1 is reproducible. If so, the PS flakes are decanted and placed on a paper towel to dry. Sorting the plastic types and recording the mass allows the calculation of the purities of the fractions.

Lastly, a separation solution is created by adding salt to tap water until saturated. The density of the solution should be around 1.2 g/cm³
. A clear container is filled with the solution before the mixed plastic test batch is added and stirred again. After stirring for 3 minutes at 300 RPM, the magnetic mixer is turned off, to allow to material to settle for 2 minutes. The floating fraction is skimmed with a strainer and rinsed under fresh water to remove the salt water from the plastic. The same is done for the sink fraction and both are placed on paper towels to dry. Then, the fractions are sorted into the plastic types to measure the masses and calculate the purities.

Calculations

NaCl water saturation (at 26 wt%):
m(NaCl)
m(H2O) + m(NaCl)

= 26% → m(NaCl) =

0.26 m(H2O)
0.74 ≈ 0.35 m(H2O)

=> mmax(NaCl(aq)) = 0.35 kgNaCl

lH2O

Plastic separation results:

Purity φfloat: | φfloat = mfloatPS/mfloat
Purity φsink: | φsink = msinkPET+PVC/msink
Purity φcombined: | φcombined = (φsink + φfloat)/2

Schedule of test with all steps required

1. Prepare batch of mixed test plastics (PS: 2.4 g, PET: 2.7 g, PVC: 1.7 g).
2. Prepare transparent container as testing environment for test a with 300 ml of tap water.
3. Add a magnetic stir bar and place the container on a magnetic mixer.
4. Set up camera to record the separation behavior over the test timeframe and start recording.
5. Start the mixer at 500 rpm. Add the mixed test plastic batch to the test container.
6. Occasionally, turn off the mixer to check if all plastic flakes sink to the bottom.
7. Once all flakes sink, slowly turn on the mixer and incrementally increase the RPM to find a point at which the PS flakes start rising in the current.
8. Leave the mixer at that RPM setting for 30 seconds.
9. Use the strainer to collect the floating flakes. Place the flakes on a paper towel to dry.
10. Pour the remaining content of the container through the strainer to extract the sink fraction and place on a paper towel as well.
11. After drying off the flakes, sort the float and sink fractions by color and measure the masses.
12. Combine the fractions into a mixed test plastic batch again.

13. Repeat steps 2-6. (Test b)
14. Once all flakes sink, remove the magnetic stir bar.
15. Pour the content of the container into the strainer. Stop after the majority of the PS flakes have entered the strainer. Place the flakes on a paper towel to dry.
16. Pour the remaining content of the container through the strainer to extract the sink fraction and place on a paper towel as well.
17. After drying off the flakes, sort the float and sink fractions by color and measure the masses.
18. Combine the fractions into a mixed test plastic batch again.
19. In the large container, prepare 400 ml of tap water.
20. Add 140 g of table salt to the water and stir until fully dissolved.
21. Add additional 10 g of table salt to the solution and stir. Even after long stirring / resting, the salt should not fully dissolve.
22. Carefully pour 300 ml of the solution into the transparent container so that no undissolved salt is transferred. (Test c)
23. Add a magnetic stir bar and place the container on a magnetic mixer.
24. Set up camera to record the separation behavior over the test timeframe and start recording.
25. Start the mixer at 300 rpm for 3 minutes. Add mixed test plastic batch to the test container.
26. After 3 minutes, turn of the magnetic mixer and let the plastic flakes settle for 2 minutes.
27. Use the strainer to collect the float fraction, carefully rinse with tap water to remove the salt, and place on a paper towel to dry.
28. Pour the content of the container trough the strainer back into the large container to collect the saline water and to remove the sink fraction.
29. Carefully rinse the sink fraction with tap water to remove the salt, and place on a paper towel to dry.
30. After drying off the flakes, sort the float and sink fractions by color and measure the masses.

Risk analysis

Potential risks associated with this test

None.

Mitigation steps

Safety glasses are worn during the whole process.

Risks after taking mitigation steps

None.

### Tools and devices required

Tool | Check-in tick
1x safety glasses | X
Paper towels | X

1x laptop | X
1x camera (phone) | X
1x timer (laptop or phone can be used) | X
1x scale | X
Containers of cut plastic flakes (PS, PET, PVC) | X
1x container for mixed plastic test batches | X
1x transparent container for tests | X
1x large container (capacity >= 0.5 l) | X
1x magnetic stir bar | X
1x magnetic mixer | X
1x strainer | X
1 l tap water | X
150 g NaCl | X
1x tweezers | X
1x calculator | X

### Testing Results

All recordings of the separation process are available here. (https://drive.google.com/drive/folders/1bQHugpcohdObDzzzYT4YMf0hfrj0wxkv?usp=drive_link)

Swirling

a: 10 s, most flakes submerged; 30 s no change; 1 min no change; turbulent stirring & manual submerging needed for complete submersion

Test | Input masses [g] | Float-output masses [g] | Sink-output masses [g]
a (160 rpm) | | PS 2.4 | PET 2.7 | PVC 1.7 | PS 0.76 | PET 0.03 | PVC 0 | 1.63 | 4.23

Tot: 6.8 (theoretically 6.8)

PS | PET | PVC

Any unexpected behaviors:

- PS flakes tend to float higher, but mix with PET on lower levels
- most material stays at low level (highest velocity due to magnetic stir bar at the bottom?)
- very difficult to extract
- impulses improve separation, PET sinks faster after impulse

Pouring

Test | Input masses [g] | Float-output masses [g] | Sink-output masses [g]
b | | PS 2.4 | PET 2.7 | PVC 1.7 | PS 0.73 | PET 0.03 | PVC 0 | 1.65 | 4.27

Tot: 6.8 (theoretically 6.8)

PS | PET | PVC

Any unexpected behaviors:

- difference in exact total output weights between tests a and b could be remaining water on the flakes

Dense sink-float separation

Separation solution:

m(H2O) = 400 g,
m(NaCl) = 140 g (enough for saturation, very little residual) + 10 g (much residual)
Test | Input masses [g] | Float-output masses [g] | Sink-output masses [g]
c | | PS 2.4 | PET 2.7 | PVC 1.7 | PS 2.39 | PET 0.08 | PVC 0 | 0 | 4.20

Tot: 6.8 (theoretically 6.8)

PS | PET | PVC

Any unexpected behaviors:

- the RPM was increased to 500, since the higher density of the medium required it
- one PET flake remaining in float has a pocket with air in it (good shredding is crucial)
- after drying, during weighting, the PET flakes were electrostatically charged

### Evaluation

The swirling and pouring methods did not display sufficiently high purities compared to the dense sink-float separation, as seen in Table 1.

One potential source of failure is the magnetic stir bar being located at the bottom of the container. This results in the highest velocity of the separation medium to occur at the bottom as well, where most of the flakes are then collected, making an extraction of just one material impossible. Moving the stirrer to the top or using pulsed actuation could improve the separation since PET and PVC flakes sink much faster in water than PS.

The pouring method exhibits very limited control of the separation with most flakes staying at the bottom of the container. This results in a good purity of the float fraction but poor values for the sink fraction, an especially unfavorable outcome since the sink fraction requires a subsequent sorting step additionally affecting the overall purity.

The best results are obtained with the dense sink-float separation. The clear separation by flake density is promoted by a lack of dynamic behaviors, allowing the flakes to separate with time. However, good shredding as a preparatory step is crucial as one PET flake remained in the float fraction due to an air bubble being caught in a small pocket of the flake skewing the density of the particle. Furthermore, this method has the disadvantage of making a high amount of salt necessary

(0.35 kgNaCl

lH2O

). These costs of roughly MWK 1000 per kilogram must be accounted for in Blantyre

(“Malawi Table Salt Prices,” n.d.).

Table 1: Purity results sorted by combined purity.

Test | Purity float | Purity sink | Purity combined
c | 96.76% | 100.00% | 98.38%
a | 96.20% | 72.18% | 84.19%
b | 96.05% | 72.13% | 84.09%

### Bibliography

Bearth, R. (2025). Plastic separation—A review [Report]. ETH Zurich. https://doi.org/10.3929/ethz-

b-000732181

David R. Lide, ed. (2005). Section 8-78. In CRC Handbook of Chemistry and Physics, Internet

Version 2005. CRC Press. https://webdelprofesor.ula.ve/ciencias/isolda/libros/handbook.pdf

Malawi Table Salt Prices. (n.d.). Selina Wamucii. Retrieved June 19, 2025, from

https://www.selinawamucii.com/insights/prices/malawi/table-salt/

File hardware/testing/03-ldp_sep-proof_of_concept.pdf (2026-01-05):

June 2025 | 1 of 5

## LDP separation - Proof of concept

Testing Document

Version 1

Date:

- Start: 19.06.2025
- End: 19.06.2025

Contents

### General description and purpose

Purpose of test

The findings of test 1 “Sink-float separation - Proof of concept” (https://docs.google.com/document/d/1ngdAf8as1NAp7tlwLvzU2yW88cCANNGC/edit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) have demonstrated the potential of high purities (> 99.9 %) of the two resulting fractions: low-density polymers (LDP) – PP, LDPE, HDPE – and high-density polymers (HDP) – PS, PET, PVC. In the subsequent steps, these fractions must be divided further into its components. This test investigates the next step for the separation of the LDP types, conducted in a similar proof-of-concept fashion (low fidelity, small scale).

Due to similar densities, a separation based on that material property is difficult (PP ~ 0.900 g/cm³ ,
LDPE ~ 0.924 g/cm³

, HDPE ~ 0.955 g/cm³
(Bearth, 2025)). Instead, the difference in the parts shape could be a useful distinguishing feature. As thin-walled plastic waste, like plastic bags or packaging, is often composed of LDPE (Shen & Worrell, 2014), its large surface area in relation to its mass could be utilized, making it susceptible to air streams. This effect can be tested by vacuuming.

Description of Test

For this test, the color coded plastic flakes from test 1 are used. There, twelve mixed plastic test batches were created with the following composition: PP 0.6 g, LDPE 0.2 g, HDPE 2.0 g, PS 2.4 g, PET 2.7 g, PVC 1.7 g (9.6 g in total). After the completion of the test, the twelve batches were combined into one and kept for later use.

This mixed plastic is now used as the test batch. It is spread out on a clean surface. Then, a vacuum cleaner equipped with a strainer at the inlet is moved over the spread-out plastic waste to extract the thin foils from the thicker pieces. For consistency, the plastic flakes pulled in by the air stream is called float fraction, while the fraction remaining on the surface is considered the sink fraction. By visually sorting the correctly and incorrectly separated flakes of the sink and the float fraction and measuring the resulting fractions’ masses, the purity of the separation can be calculated.

Calculations

Plastic separation results:

Purity φfloat: | φfloat = mfloatLDPE /mfloat
Purity φsink: | φsink = msinknot LDPE /msink
Purity φcombined: | φcombined = (φsink + φfloat)/2

Schedule of test with all steps required

1. Attach a strainer to the inlet of the vacuum cleaner (concave facing outward).
2. Test the existence of airflow through the strainer with your hand. (lowest intensity)
3. Spread 30 g of the mixed plastic flakes on a clean surface. (Test a1)
4. Set up camera to record the separation behavior over the test timeframe and start recording.
5. Move the vacuum cleaner with the strainer over the mixed plastic while keeping a distance of 35 mm.
6. Collect the aspirated fraction in a separate container.
7. Sort the float and sink fractions by color and measure the masses.

8. Mix the fractions well.
9. Repeat steps 3-7. (Test a2)

Risk analysis

Potential risks associated with this test

None.

Mitigation steps

None.

Risks after taking mitigation steps

None.

### Tools and devices required

Tool | Check-in tick
1x laptop | X
1x camera (phone) | X
1x scale | X
Remaining mixed plastic of test 1 | X
1x container | X
1x strainer | X
Adhesive tape | X
1x tweezers | X
1x calculator | X
1x flat surface | X
1x vacuum cleaner | X

### Testing Results

All recordings of the separation process and pictures of the results are available here. (https://drive.google.com/drive/folders/1Rhx-80w27GTtAWJXGa5zpuX1rzfctkzG?usp=drive_link)

Strainer prep and vacuum test:

Very high airflow even at minimum suction

Mixed plastic ratio from test 1:

PP 0.6 | LDPE 0.2 | HDPE 2.0
PS 2.4 | PET 2.7 | PVC 1.7

Separation:

Test | Float-output masses [g] | Sink-output masses [g]
a1 | | PP 0 | LDPE 0.492 | HDPE 0 | LDPE 0.270
| | PS 0.075 | PET 0 | PVC 0 | Others 29.1
a2 | | PP 0 | LDPE 0.751 | HDPE 0 | LDPE 0.001
| | PS 0.049 | PET 0.074 | PVC 0 | Others 29.06

Note: for a2, the strainer was fitted with a solder tin wire with a length of 35 mm to ensure a constant distance to the surface and induce movement within the flakes.

Any unexpected behaviors:

- Very high specificity (almost only foils picked up)
- Fast clogging
- Foils must be on top; if underneath other plastic flakes, it does not move
- Adhesive residual on plastic pieces impedes the separation possibility
- a1: only 3 flakes of PS in float fraction
- a2: when flakes are moved slightly (with tip of solder tin wire) + constant distance to surface kept by wire almost all LDPE was collected.
- a2: especially for last few suctions, relatively more PET and PS was picked up
→ high purity of LDPE foil OR high purity of sink fraction

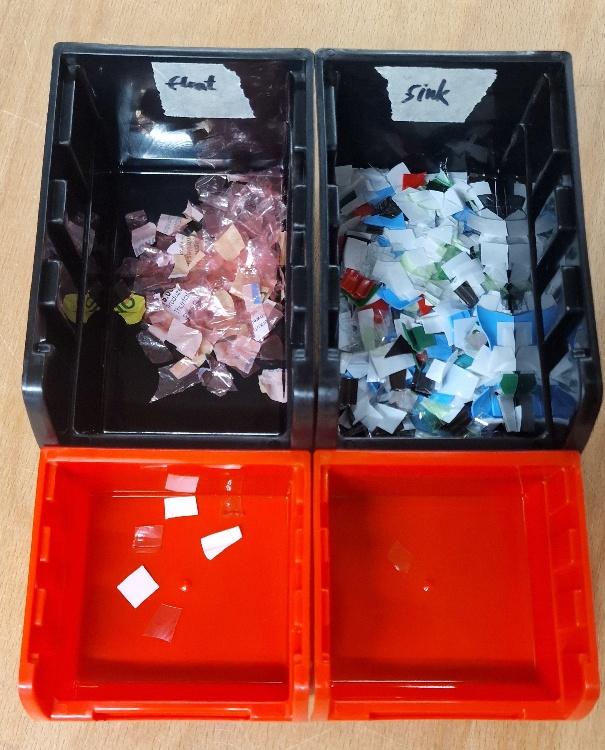
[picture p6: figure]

- a2: only one flake of LDPE in sink fraction, three flakes of PS and three flakes of PET in float fraction

Figure 1: Resulting fractions of run a2; correctly classified flakes in black containers, misclassified flakes in red containers.

### Evaluation

Generally, this method is well suited to extract foil flakes (see Table 1). However, due to the low mass of the plastic foil, the purity of the sink fraction is not a good measurement. Therefore, the number of misclassified flakes were counted as well.

Both runs exhibited a high specificity towards collecting foil flakes. In the first run, many LDPE flakes were covered by particles of other material which resulted in the inability to be picked out by the vacuum. At the same time, only three PS flakes were aspirated. For the second run, a solder wire with a length of 35 mm was attached to the end. This allowed a constant distance from the surface and induced motion between the flakes. Here, the number of correctly aspirated flakes was much higher with only one being left in the sink fraction. While the picked-up flakes were almost purely LDPE in the beginning of the separation procedure, the further the extraction got towards no LDPE in the sink portion, the more PS and PET flakes were picked up as well. This is an indication that the targets of high purity for the floating fraction and the sinking fraction are conflicting.

Since the sink fraction has to undergo an additional step after this procedure and their recycling capabilities are substantially larger than for LDPE, targeting maximized purity for the sink fraction could be beneficial for a prototype.

Important for this separation method is a constant distance to the flakes (constant air stream), motion within the flakes to loosen the LDPE flakes that are stuck underneath another material, and adhesives from prior use of the plastic being removed beforehand.

Table 1: Purity results and number of misclassified flakes, sorted by combined purity.

Test | Purity float | Purity sink | Purity combined | Misclassified flakes in float fraction | Misclassified flakes in sink fraction
a2 | 85.93% | 100.00% | 92.96% | PS: 3, PET: 3 | LDPE: 1
a1 | 86.77% | 99.08% | 92.93% | PS: 3 | LDPE: >20

### Bibliography

Bearth, R. (2025). Plastic separation—A review [Report]. ETH Zurich. https://doi.org/10.3929/ethz-

b-000732181

Shen, L., & Worrell, E. (2014). Plastic Recycling. In E. Worrell & M. A. Reuter (Eds.), Handbook of

Recycling (pp. 179–190). Elsevier. https://doi.org/10.1016/B978-0-12-396459-5.00013-1

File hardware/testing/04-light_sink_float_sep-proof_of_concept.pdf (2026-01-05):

July 2025 | 1 of 7

## Light sink float separation - Proof of concept

Testing Document

Version 1

Date:

- Start: 03.07.2025
- End: 07.07.2025

Contents

### General description and purpose

Purpose of test

By combining the results of test 1 “Sink-float separation – Proof of concept” (https://docs.google.com/document/d/1ngdAf8as1NAp7tlwLvzU2yW88cCANNGC/edit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) which grouped the mixed plastic waste in low-density polymers (LDP) – PP, LDPE, HDPE – and high-density polymers (HDP) – PS, PET, PVC – with the results of test 3 “LDP separation – Proof of concept” (https://docs.google.com/document/d/1HC1k_TJNJtIJ4P20dA4lNdKVPlkHwTi-/edit?usp=sharing&rtpof=true&sd=true) which extracted the LDPE foils from the LDP mix, a blend of PP and HDPE remains. This test assesses the separation of these two types by sink-float separation using an ethanol-water mixture as a density-adjusted separation medium. Additionally, the evaporation of the medium over time is investigated as well as the thread of ignition when using ethanol.

Description of Test

For this test, the color-coded plastic flakes from test 1 are used. One mixed test plastic batch is created from the PP and the HDPE flakes, using 1.5 g of each material.

The densities of the materials are 0.900-0.910 g/cm³

for PP and 0.940-0.970 g/cm³ for HDPE
(SpecialChem SA, 2025) which lie within the density boundaries of the separation solution (100% ethanol: ρ

20

0.78932 g/cm³
, 100% water: ρ

20

0.99820 g/cm³
(Rumble, 2025b)). As a separation medium, an ethanol-water solution is prepared for which a temperature of 20-25 °C is assumed. At this temperature range, the interesting ethanol mass % range is shown in Table 1.

Table 1: Density of Ethanol–Water Mixtures at different percentages and temperatures (interpolated values in red) (Rumble, 2025b)

Ethanol mass % | 20 [g/cm³ ρ ] | 25 [g/cm³ ρ ] | Ethanol volume %
35 | 0.94491 | 0.94143 | 40.5
40 | 0.93515 | 0.93145 | 45.7
44.13 | 0.92650 | 0.92266 | 50
45 | 0.92469 | 0.92082 | 50.9
50 | 0.91381 | 0.90982 | 55.8
90 | 0.81795 | 0.81360 | 91.9
94 | 0.80721 | 0.80263 | 95.2
95 | 0.80422 | 0.79989 | 96.0

To leave margin for inaccuracy and account for some evaporation of the ethanol while simultaneously minimizing the required amount of ethanol, an ethanol volume % of 50 % is targeted.

The ethanol used is “Ethanol denatured with Ketone 94 %” from the HCI-Shop, ETH Zurich. Since the composition is not further specified, it is assumed that it consist of 94 % ethanol and 6 % methyl ethyl ketone (MEK) which is the ketone commonly used for denaturing in the EU (“Vergällung,” 2024). Since the density of MEK (ρ

25

0.7999 g/cm³
(Rumble, 2025a)) is similar to the one of ethanol, the simplification is made that the mixture consists of 100% ethanol.

To create the separation medium of ethanol-water mixture with an ethanol volume % of 50 %, equal volumes of ethanol and water (150 ml each) are added to a beaker. To verify the ethanol content with the hydrometer, 100 ml of the mixture are transferred to a measuring cylinder. After recording the value, the liquid is returned to the beaker. Then, the mixed plastic test batch is added and stirred with a magnetic mixer. After stirring for 3 minutes at 300 RPM, the magnetic mixer is turned off to allow the material to settle for 2 minutes. The floating fraction is skimmed with a strainer. The same is done for the sink fraction while transferring the separation solution to another beaker and both extracted fractions are placed on paper towels to dry. Subsequently, the fractions are sorted into the plastic types to measure the masses and calculate the purities.

To assess the evaporation rate of the ethanol under different conditions, the separation solution is then transferred to two identical measuring cylinders (100 ml each). After the alcohol content and mass is recorded with the hydrometer for each batch, one of the cylinders is sealed with a chemically resistant glove. The alcohol content and mass are recorded for both batches three more times.

Lastly, it is attempted to light a small quantity of the separation medium (50 vol % ethanol) as well as a small quantity of the denatured ethanol (94 vol % ethanol) with a match to test the hazard of ethanol ignition at different ratios.

Calculations

Conversion from ethanol mass % (a) to ethanol volume % (b):

% w/w: a =

mE
mW+mE

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
% v/v: b =

VE
VW+VE

→

VE
VW

=

b
1−b
a
1 − a

ρW
ρE

=

b
1 − b

⇒ b =

1
1 − a
a

ρE
ρW

+ 1

Plastic separation results:

Purity φfloat: | φfloat = mfloatPS/mfloat
Purity φsink: | φsink = msinkPET+PVC/msink
Purity φcombined: | φcombined = (φsink + φfloat)/2

Schedule of test with all steps required

1. Prepare batch of mixed test plastics (PP: 1.5 g, HDPE: 1.5 g).
2. Prepare the separation solution in a beaker with 150 ml of ethanol and 150 ml of tap water.
3. Transfer 100 ml of the solution to a measuring cylinder.
4. Record the ethanol content with the hydrometer.
5. Return the solution to the beaker.
6. Add a magnetic stir bar and place the container on a magnetic mixer.
7. Set up camera to record the separation behavior over the test timeframe and start recording.
8. Start the mixer at 300 rpm for 3 minutes. Add mixed test plastic batch to the test container.
9. After 3 minutes, turn of the magnetic mixer and let the plastic flakes settle for 2 minutes.

10. Use the strainer to collect the float fraction and place on a paper towel to dry.
11. Pour the content of the container trough the strainer into another beaker to collect the separation solution and to remove the sink fraction.
12. Place the sink fraction on a paper towel to dry.
13. After drying off the flakes, sort the float and sink fractions by color and measure the masses.
14. Transfer 2x 100 ml of the separation solution in two identical measuring cylinders.
15. Record the masses and the ethanol contents of each batch.
16. Seal one of the cylinders with a chemically resistant glove.
17. Repeat steps 15 and 16 after 1.5, 5, and 11 hours.
18. Prepare a small quantity of the separation solution in a beaker.
19. Set up the camera to record ignition and combustion and start recording.
20. Light a match and drop the match into the filled beaker.
21. Once the flame has extinguished, wait until the glass of the beaker has returned to room temperature and remove any leftover liquid inside.
22. Repeat steps 18-21, substituting the separation solution with the denatured ethanol.

Risk analysis

Potential risks associated with this test

Ethanol is highly flammable in liquid and vapor form and can cause serious eye irritation.

Mitigation steps

Only small amounts of ethanol is used at a time, the tests are done in a ventilated area, possible sources of fire are removed, and a fire blanket is prepared.

Safety glasses are worn at any time.

For the ignition tests, only small quantities are used, and the test is performed in a large space with any other flammable material removed.

Risks after taking mitigation steps

None.

### Tools and devices required

Tool | Check-in tick
1x safety glasses | X
1x fire blanket | X
Paper towels | X
1x laptop | X
1x camera (phone) | X

1x timer (laptop or phone can be used) | X
1x scale | X
Containers of cut plastic flakes (PP, HDPE) | X
1x container for mixed plastic test batches | X
2x transparent beaker | X
2x measuring cylinders | X
1x hydrometer | X
1x magnetic stir bar | X
1x magnetic mixer | X
1x strainer | X
1x matchbox | X
150 ml tap water | X
150 ml ethanol | X
1x nitrile rubber glove | X
1x tweezers | X
1x calculator | X

### Testing Results

All recordings and pictures of the tests are available here. (https://drive.google.com/drive/folders/1W8XrIZIjnylG2JQjMky51m95QZCBeqFO?usp=drive_link)

Plastic separation

Mass of beaker: 140.5 g.

Test | Input masses [g] | Float-output masses [g] | Sink-output masses [g]
a (160 rpm) | | PP 1.5 | HDPE 1.5 | PP 1.5 | HDPE 0 | PP 0 | HDPE 1.5

Tot: 3.0 (theoretically 3.0)

Any unexpected behaviors:

- No residual of separation solution measurable on plastic flakes after drying

Ethanol evaporation

Mass of measuring cylinders: 41.7 g each.

Batch | Time of measurement | Total mass [g] (with cylinder) | Ethanol content [vol %]
Initial solution | 10:53 | 133.7¹ | 52
a (sealed) | 11:11 | 134.4 | 48
b | 11:11 | 134.4 | 48
a (sealed) | 12:46 | 134.1 | 47
b | 12:46 | 133.9 | 47
a (sealed) | 16:06 | 133.8 | 46
b | 16:06 | 133.6 | 46
a (sealed) | 22:49 | 133.6 | 46
b | 22:49 | 133.3 | 46
a (sealed) | 15:00 (+3 days) | 133.1 | 46
b | 15:01 (+3 days) | 131.3 | 45

Ethanol ignition

At 50 vol % ethanol, the solution was not ignited by the match. Instead, the match extinguished immediately when coming in contact with the solution. With an alcohol content of 94 vol %, the denatured ethanol exhibited a long lasting, almost invisible flame.

1 The liquid was transferred back into the beaker to conduct the plastic separation test after this measurement. For the next observations in this column, the measuring cylinders were filled anew, resulting in a different starting weight.

### Evaluation

The results obtained for the sink-float separation show an ideal separation of the PP flakes (float fraction) from the HDPE flakes (sink fraction) (see Table 2).

Table 2: Purity results sorted by combined purity.

Purity float | Purity sink | Purity combined
100.00% | 100.00% | 100.00%

The evaporation test shows a decrease of mass and ethanol content of the separation solution over time. While only small in this case, the evaporation rate is dependent on the surface area (Carrier et al., 2016). Therefore, sealing is recommended for larger containers.

Although the solution at 50 vol % ethanol could not be ignited during the testing, caution should still be exercised when handling ethanol. All sources of ignition should be avoided in the area of use.

### Bibliography

Carrier, O., Shahidzadeh-Bonn, N., Zargar, R., Aytouna, M., Habibi, M., Eggers, J., & Bonn, D.

(2016). Evaporation of water: Evaporation rate and collective effects. Journal of Fluid

Mechanics, 798, 774–786. https://doi.org/10.1017/jfm.2016.356

Rumble, | J. | R. | (2025a). | Butanone. | CHEMnetBASE.

https://hbcp.chemnetbase.com/chemical/ChemicalSearchResults.xhtml?dswid=-8099

Rumble, J. R. (2025b). DENSITY OF ETHANOL–WATER MIXTURES. CHEMnetBASE.

https://hbcp.chemnetbase.com/documents/06_66/06_66_0001.xhtml?dswid=8070

SpecialChem | SA. | (2025). | Density | of | Plastics: | Technical | Properties. | Omnexus.

https://omnexus.specialchem.com/polymer-property/density

Vergällung. | | | (2024). | | | In | | Wikipedia.

https://de.wikipedia.org/w/index.php?title=Verg%C3%A4llung&oldid=245460291

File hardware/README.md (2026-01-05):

---
README for `./hardware`
---

The hardware directory contains two sub-directories: `design` and `testing`.

# `hardware/design`

This directory contains the design files for the developed prototype. It includes 3D part files, technical drawings, and others to reproduce the designs.
For further information see the `README.md` file in the `./hardware/design` directory.

# `hardware/testing`

In this directory, detailed documentation including testing description, schedule, tools, results, and evaluation are provided in this directory.
For further information see the `README.md` file in the `./hardware/testing` directory.

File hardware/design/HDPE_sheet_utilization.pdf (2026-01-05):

New HDPE sheets
990 x 990

Basin wall
(4x per basin) Basin bottom (1x per basin)

Lid
(1x per lid)

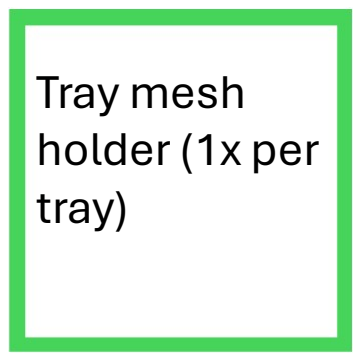
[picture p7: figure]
Tray mesh holder (1x per tray)

Tray side
sheet (2x
per tray)

Tray grip
sheet (2x per
tray)

Lid handles
(2x per lid)

# 410x20 450x20 450x20

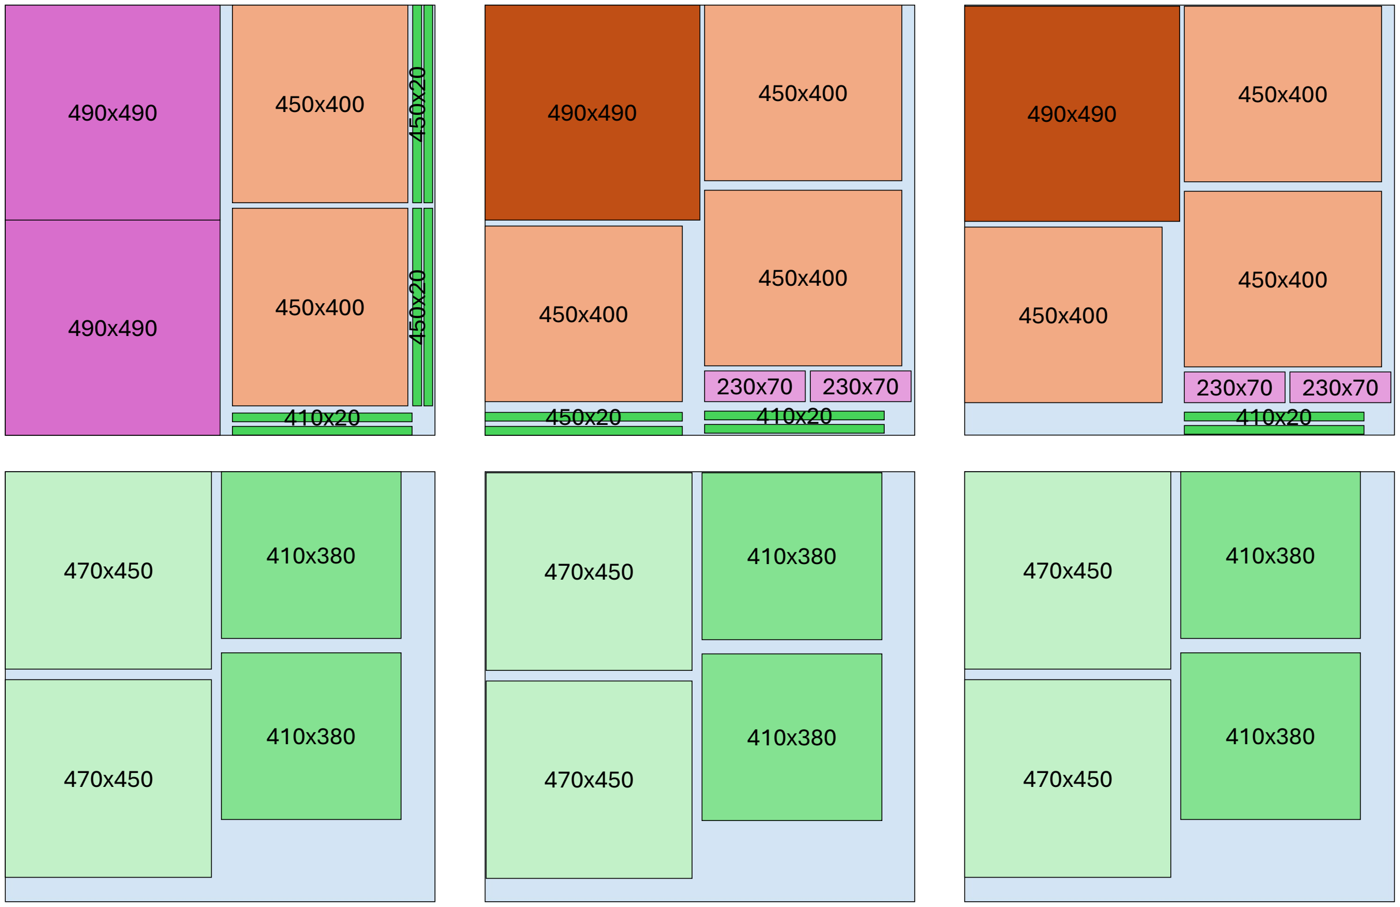
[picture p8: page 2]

490x490

490x490

450x400

450x400 490x490

410x380

410x380
470x450

470x450

450x400

230x70 230x70
450x20

450x400

450x400

410x20

490x490

450x400

230x70 230x70

450x400

450x400

410x20

410x380

410x380
470x450

470x450

410x380

410x380
470x450

470x450

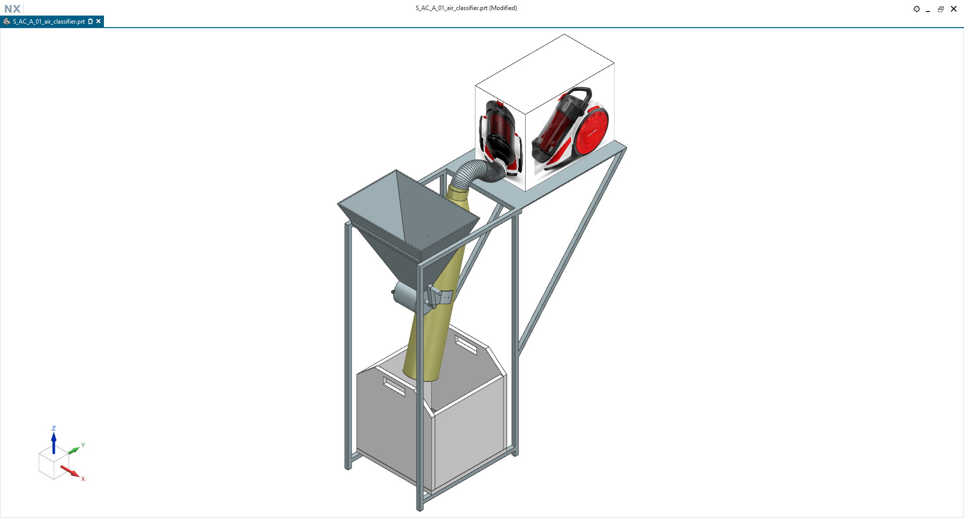
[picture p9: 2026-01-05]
media/design/air_classifier-isometric.png

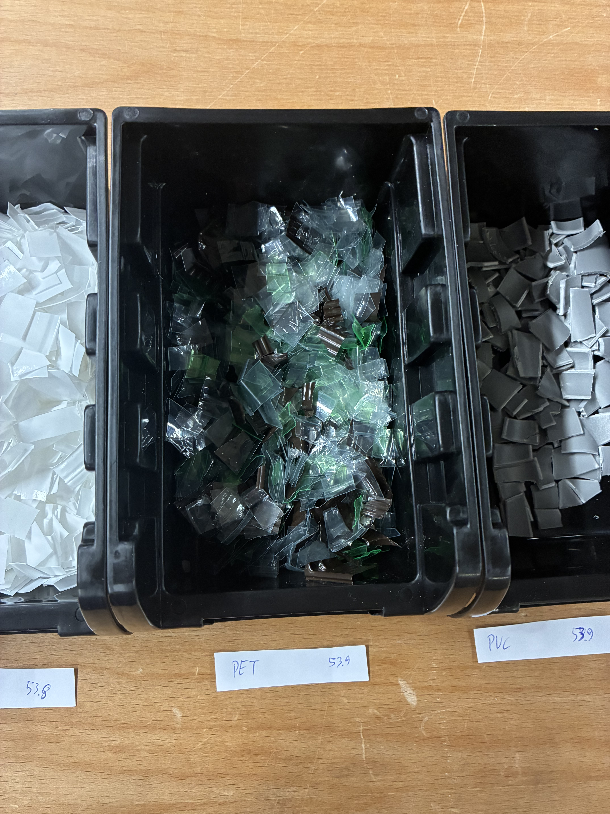
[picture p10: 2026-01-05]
media/testing/01-sink_float_sep-proof_of_concept/preparation-plastic_types-PET.jpeg

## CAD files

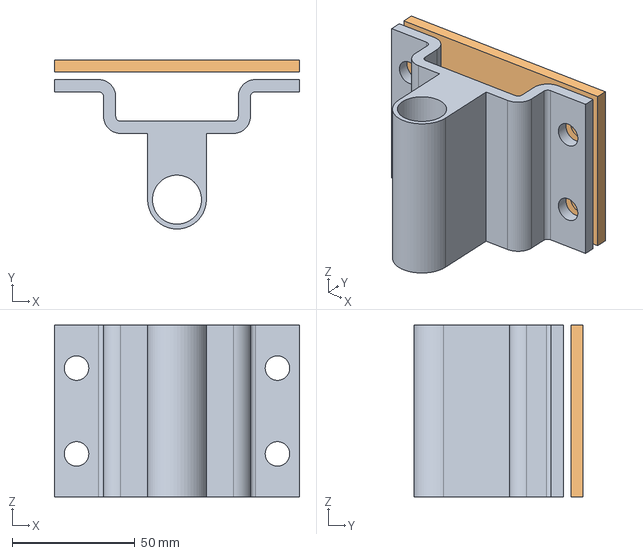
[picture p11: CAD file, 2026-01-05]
hardware/design/S_separation/S_SF_M_08_stirrer_mount.stp
100.0 x 69.0 x 70.0 mm

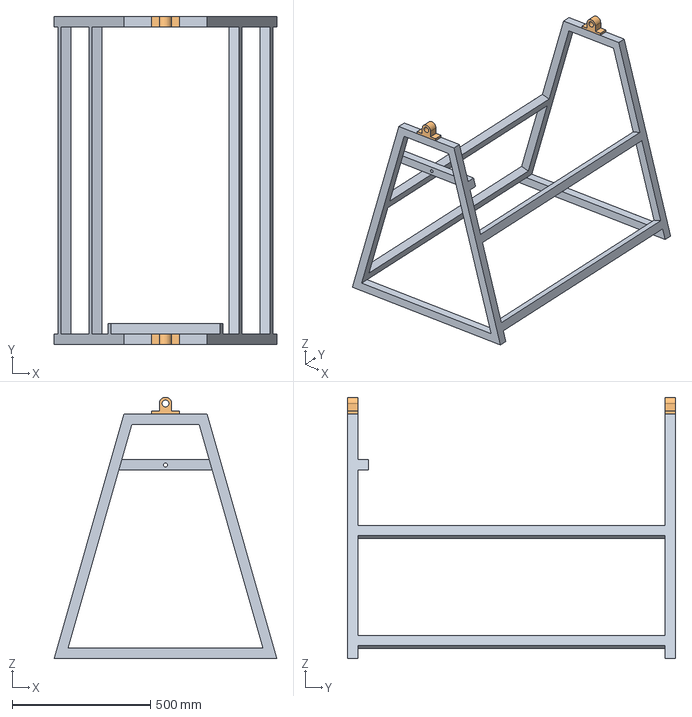
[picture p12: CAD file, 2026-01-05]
hardware/design/W_washing/W_WS_M_02_frame.stp
805.0 x 1185.0 x 944.5 mm

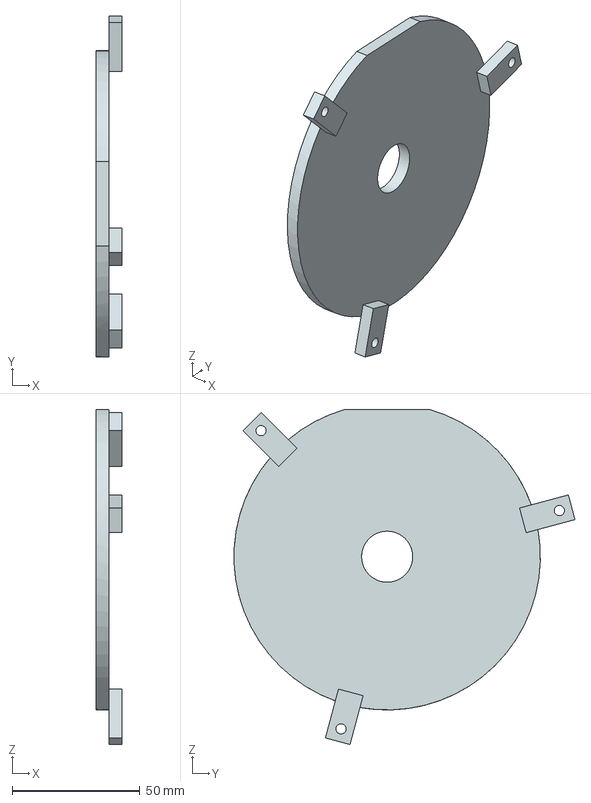
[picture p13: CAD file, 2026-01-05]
hardware/design/S_separation/S_AC_M_08_feeder_drum_lid.stp
10.0 x 133.5 x 131.2 mm

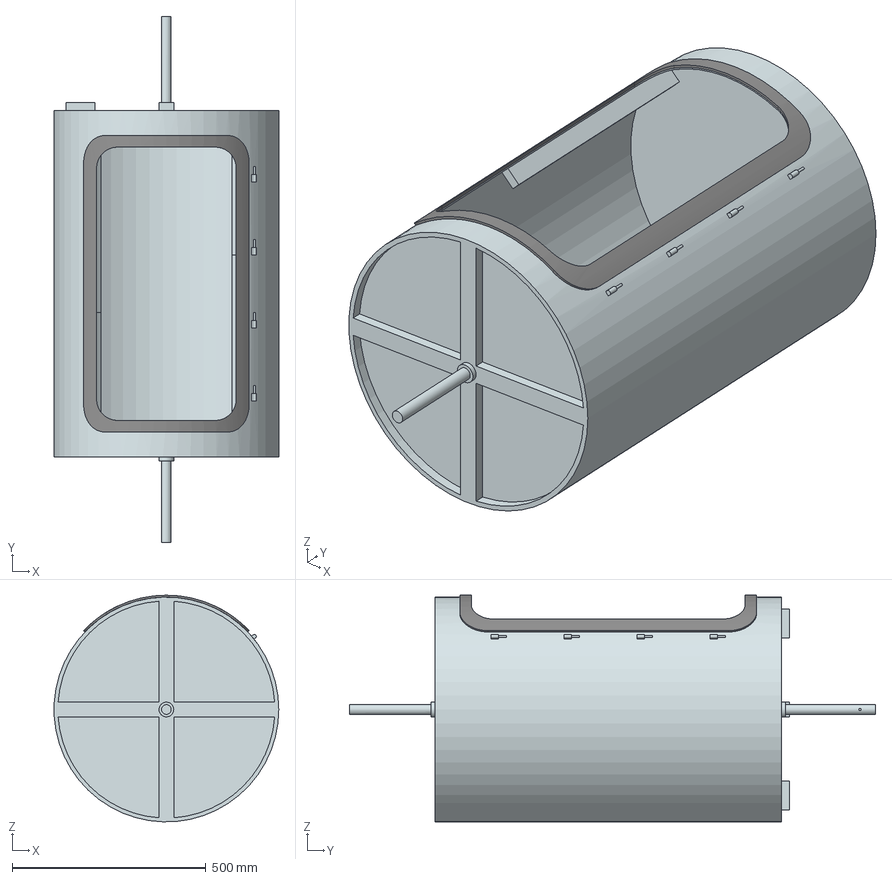
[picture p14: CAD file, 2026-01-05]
hardware/design/W_washing/W_WS_M_01_drum.stp
579.4 x 1357.0 x 584.9 mm

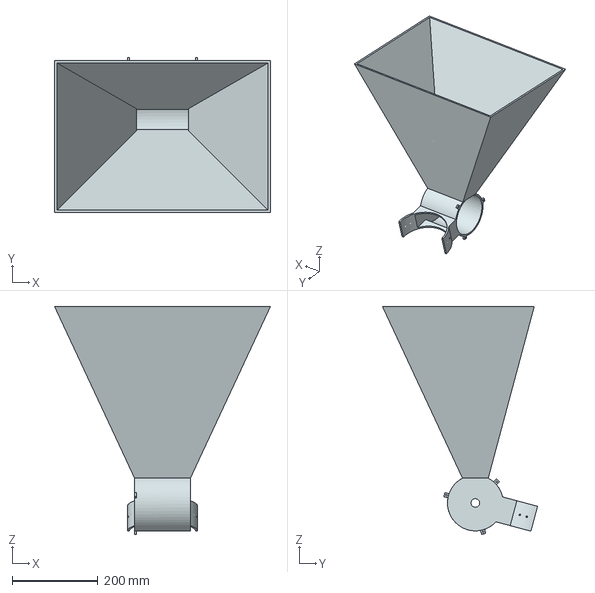
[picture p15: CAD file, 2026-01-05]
hardware/design/S_separation/S_AC_M_03_feeder.stp
503.0 x 361.4 x 531.2 mm

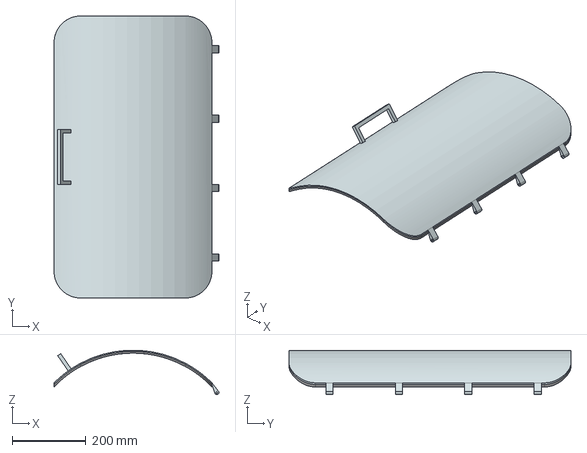
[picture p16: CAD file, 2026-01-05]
hardware/design/W_washing/W_WS_M_04_door.stp
447.2 x 765.0 x 120.3 mm

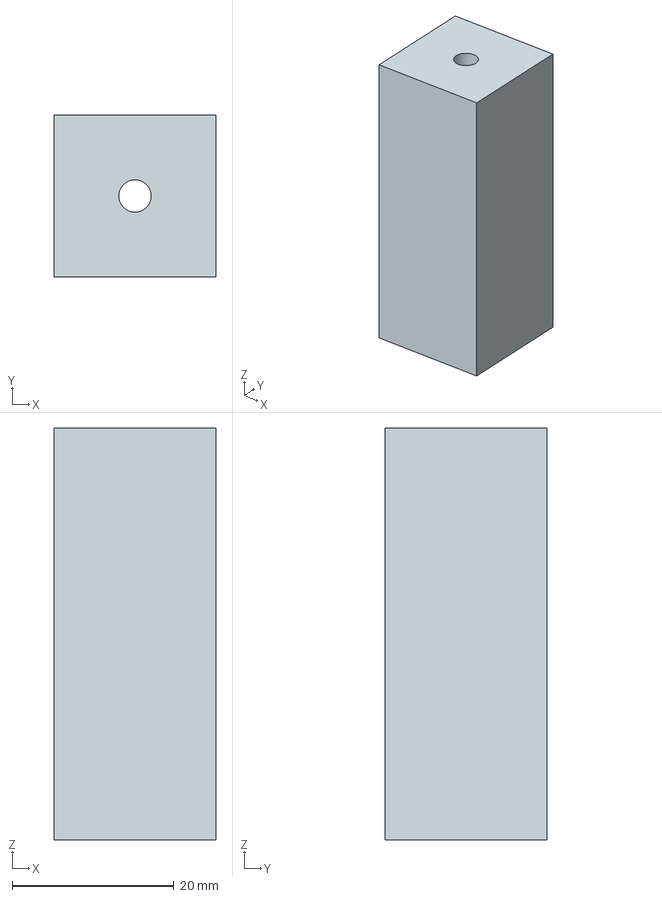
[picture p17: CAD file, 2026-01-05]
hardware/design/S_separation/S_AC_M_07_tube_support.stp
20.0 x 20.0 x 50.9 mm

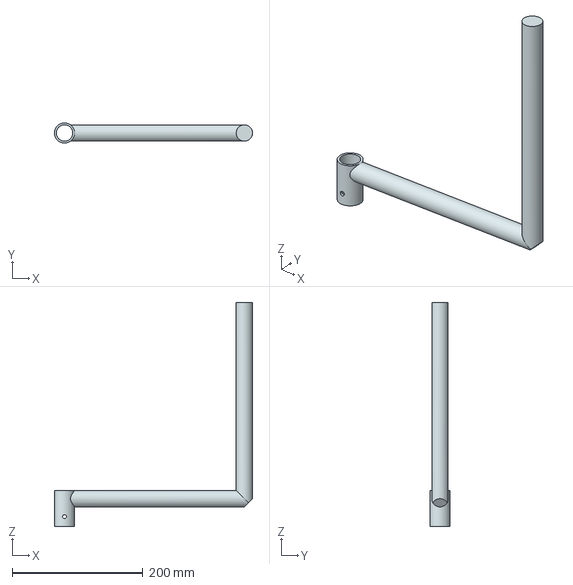
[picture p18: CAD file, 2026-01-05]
hardware/design/W_washing/W_WS_M_03_crank.stp
303.0 x 31.0 x 342.5 mm

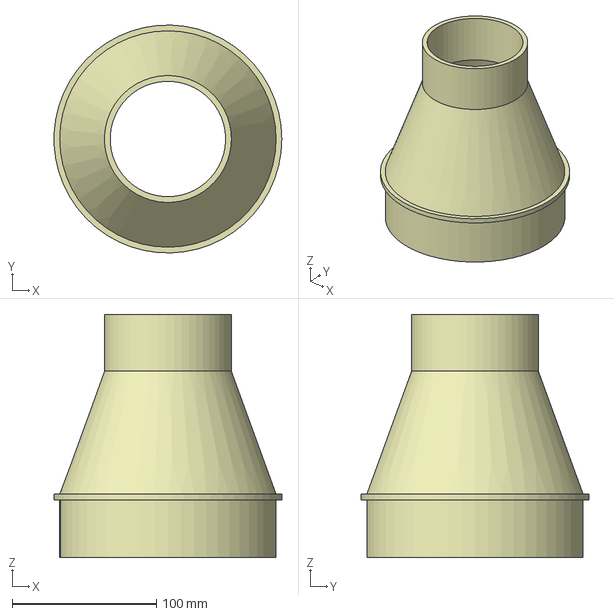
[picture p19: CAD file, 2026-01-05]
hardware/design/S_separation/S_AC_M_04_tube_vacuum_connector.stp
157.9 x 157.9 x 168.5 mm

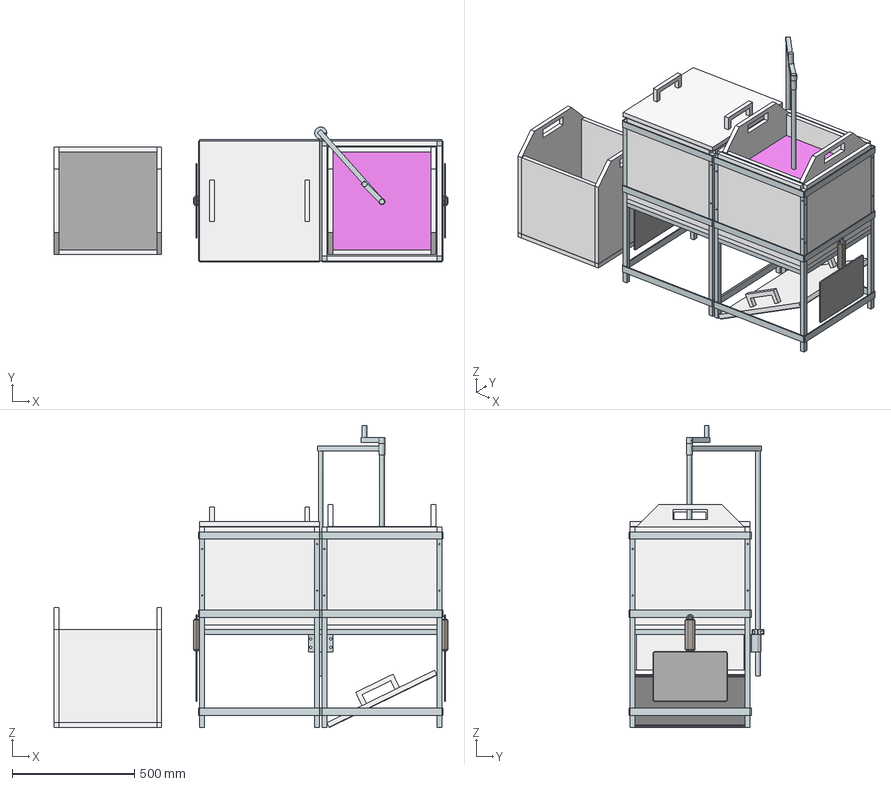
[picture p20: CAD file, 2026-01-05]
hardware/design/S_separation/S_SF_A_01_sink_float.stp
1610.0 x 552.0 x 1235.0 mm
S_SF_M_01_basin x 2
S_SF_M_02_frame x 2
S_SF_M_03_tray x 2
S_SF_M_04_scoop x 2
S_SF_M_05_lid x 2
S_SF_M_06_stirrer
S_SF_M_07_stirrer_holder
S_SF_M_08_stirrer_mount
S_SF_M_09_stirrer_holder_clamp
S_AC_M_06_crank

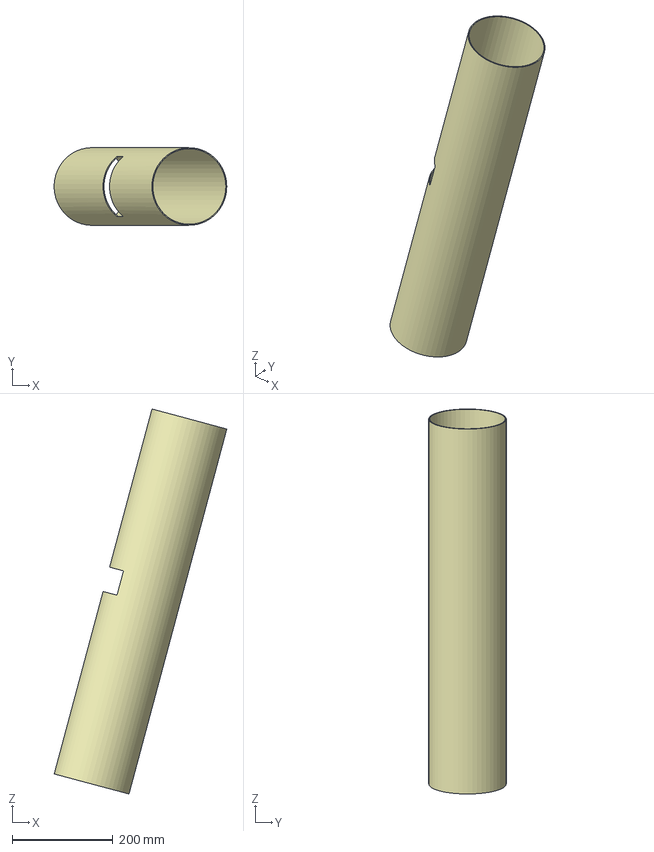
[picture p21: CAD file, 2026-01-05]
hardware/design/S_separation/S_AC_M_02_tube.stp
342.7 x 153.9 x 764.3 mm

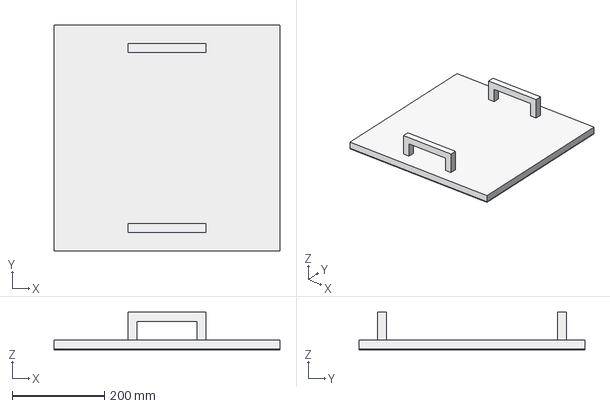
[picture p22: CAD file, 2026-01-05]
hardware/design/S_separation/S_SF_M_05_lid.stp
490.0 x 490.0 x 82.0 mm

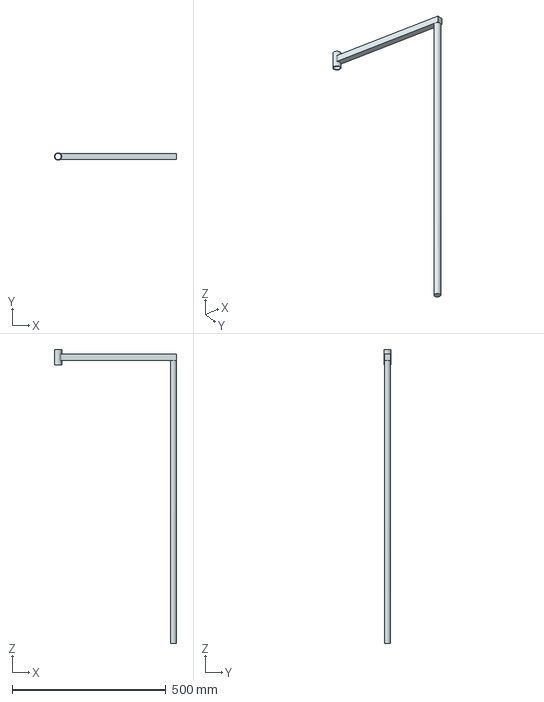
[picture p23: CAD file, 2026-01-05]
hardware/design/S_separation/S_SF_M_07_stirrer_holder.stp
397.0 x 24.0 x 955.0 mm

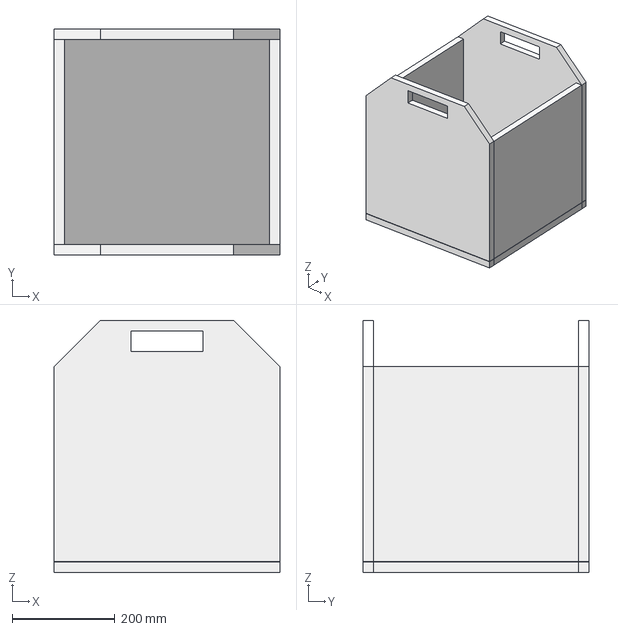
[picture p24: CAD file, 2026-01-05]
hardware/design/S_separation/S_SF_M_03_tray.stp
440.0 x 440.0 x 491.0 mm

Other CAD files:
hardware/design/S_separation/S_AC_M_06_crank.stp
hardware/design/S_separation/S_SF_M_06_stirrer.stp
hardware/design/S_separation/S_AC_M_05_feeder_drum.stp
hardware/design/S_separation/S_AC_M_01_frame.stp
hardware/design/A_full_process_line.prt
hardware/design/S_separation/S_AC_A_01_air_classifier.prt
hardware/design/S_separation/S_AC_A_01_air_classifier.stp
hardware/design/S_separation/S_AC_M_01_frame.prt
hardware/design/S_separation/S_AC_M_01_frame_dwg_1-1.prt
hardware/design/S_separation/S_AC_M_02_tube.prt
hardware/design/S_separation/S_AC_M_02_tube_dwg_1-1.prt
hardware/design/S_separation/S_AC_M_03_feeder.prt
hardware/design/S_separation/S_AC_M_03_feeder_dwg_1-1.prt
hardware/design/S_separation/S_AC_M_04_tube_vacuum_connector.prt
hardware/design/S_separation/S_AC_M_04_tube_vacuum_connector_dwg_1-1.prt
hardware/design/S_separation/S_AC_M_05_feeder_drum.prt
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

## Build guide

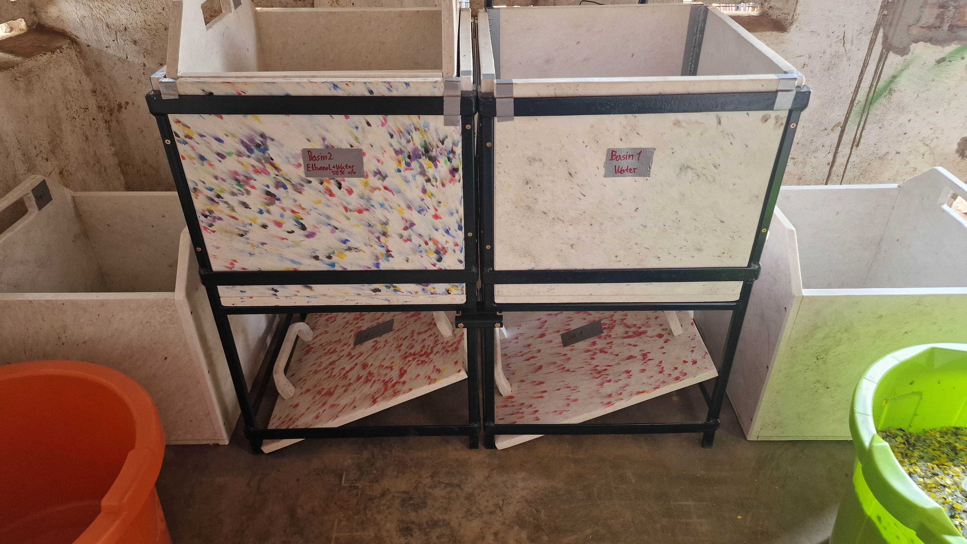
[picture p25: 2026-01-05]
media/testing/07-sink_float_prototype_test/separation_setup_4.jpg

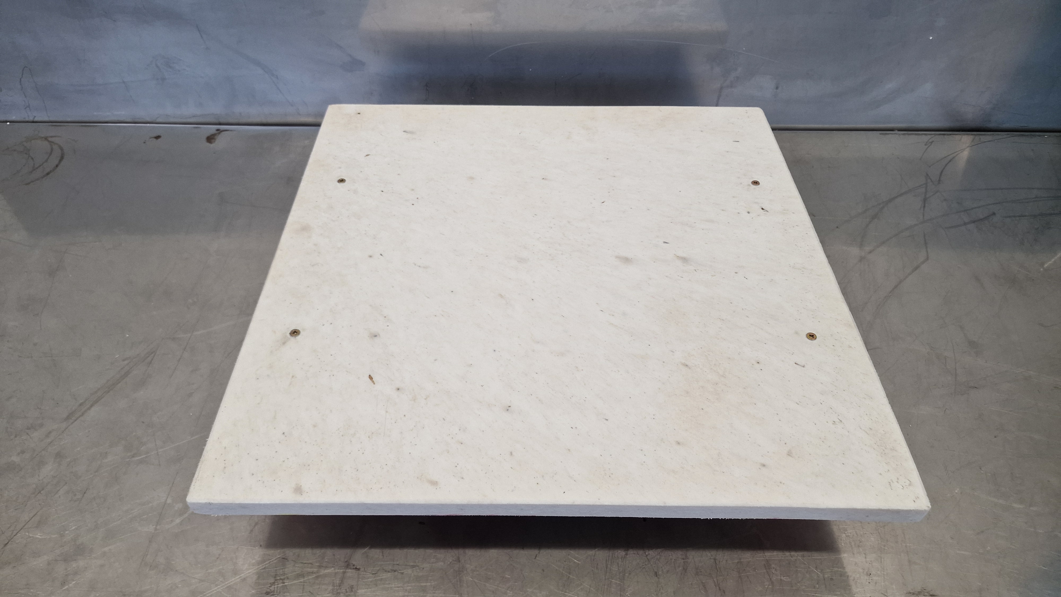
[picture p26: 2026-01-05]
media/manufacturing/lid-handle_placement.jpg

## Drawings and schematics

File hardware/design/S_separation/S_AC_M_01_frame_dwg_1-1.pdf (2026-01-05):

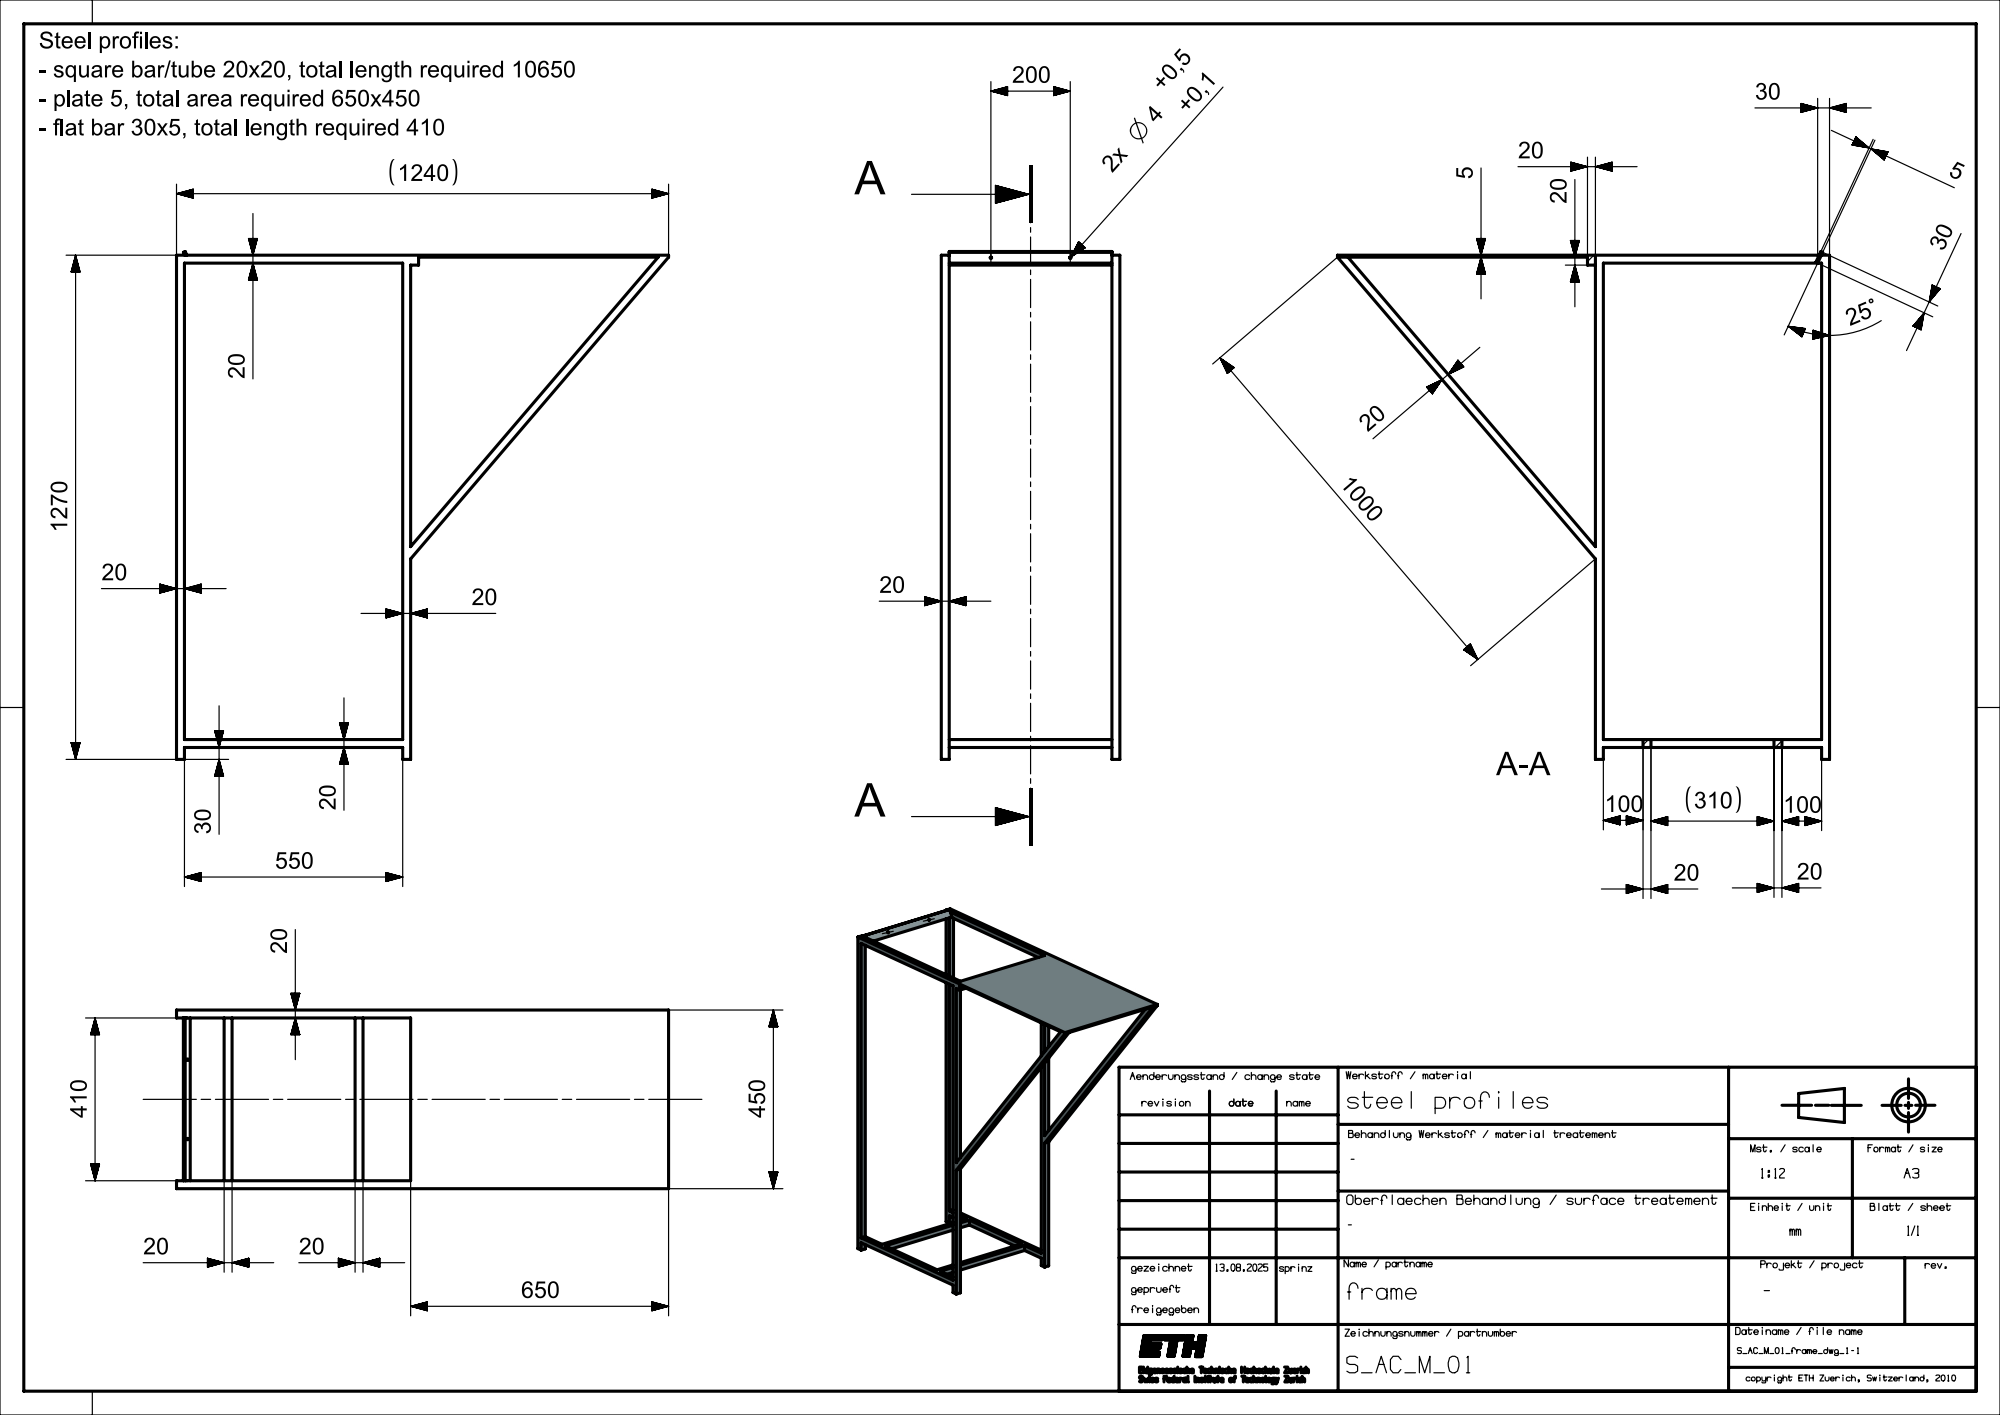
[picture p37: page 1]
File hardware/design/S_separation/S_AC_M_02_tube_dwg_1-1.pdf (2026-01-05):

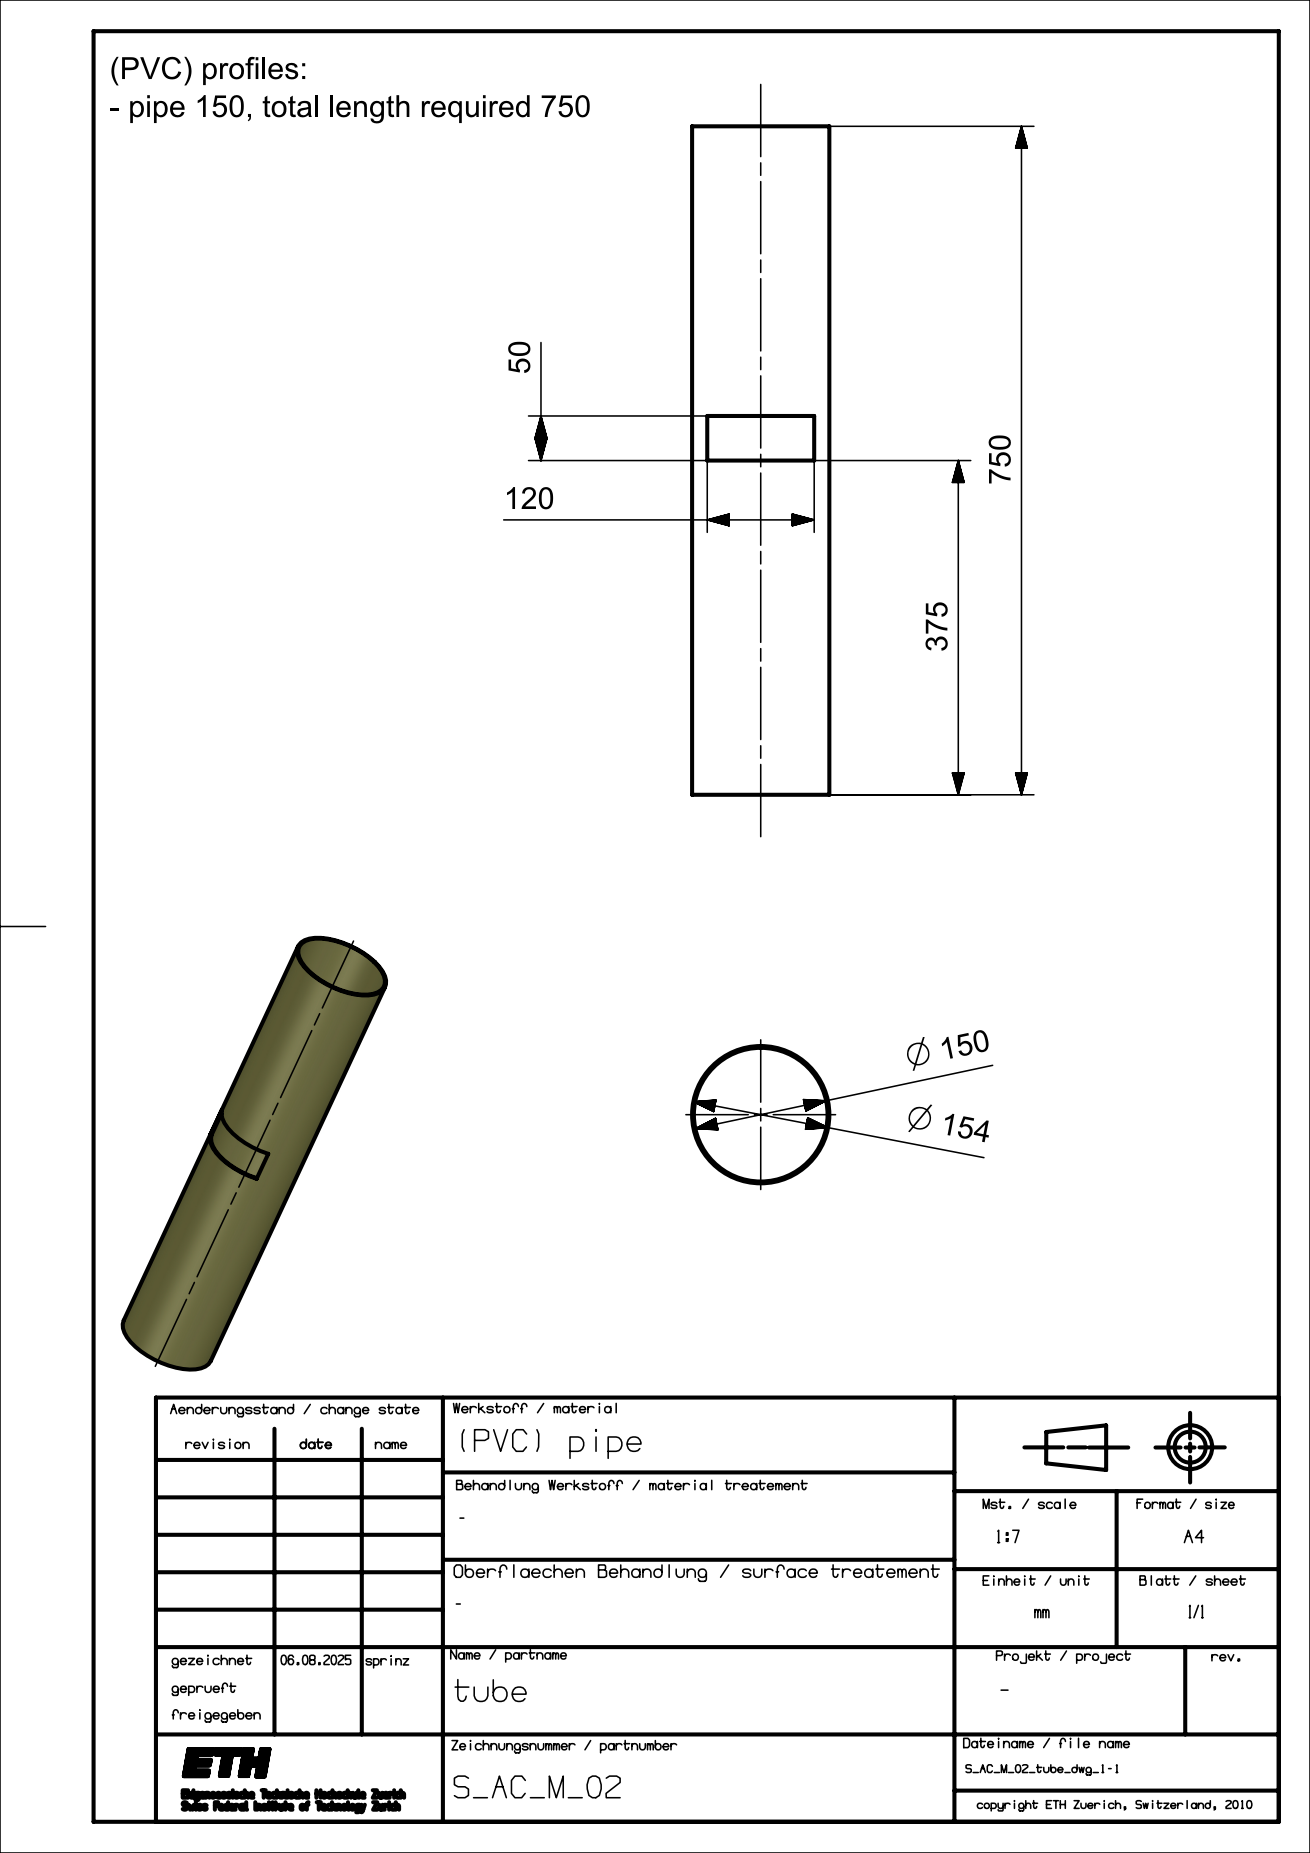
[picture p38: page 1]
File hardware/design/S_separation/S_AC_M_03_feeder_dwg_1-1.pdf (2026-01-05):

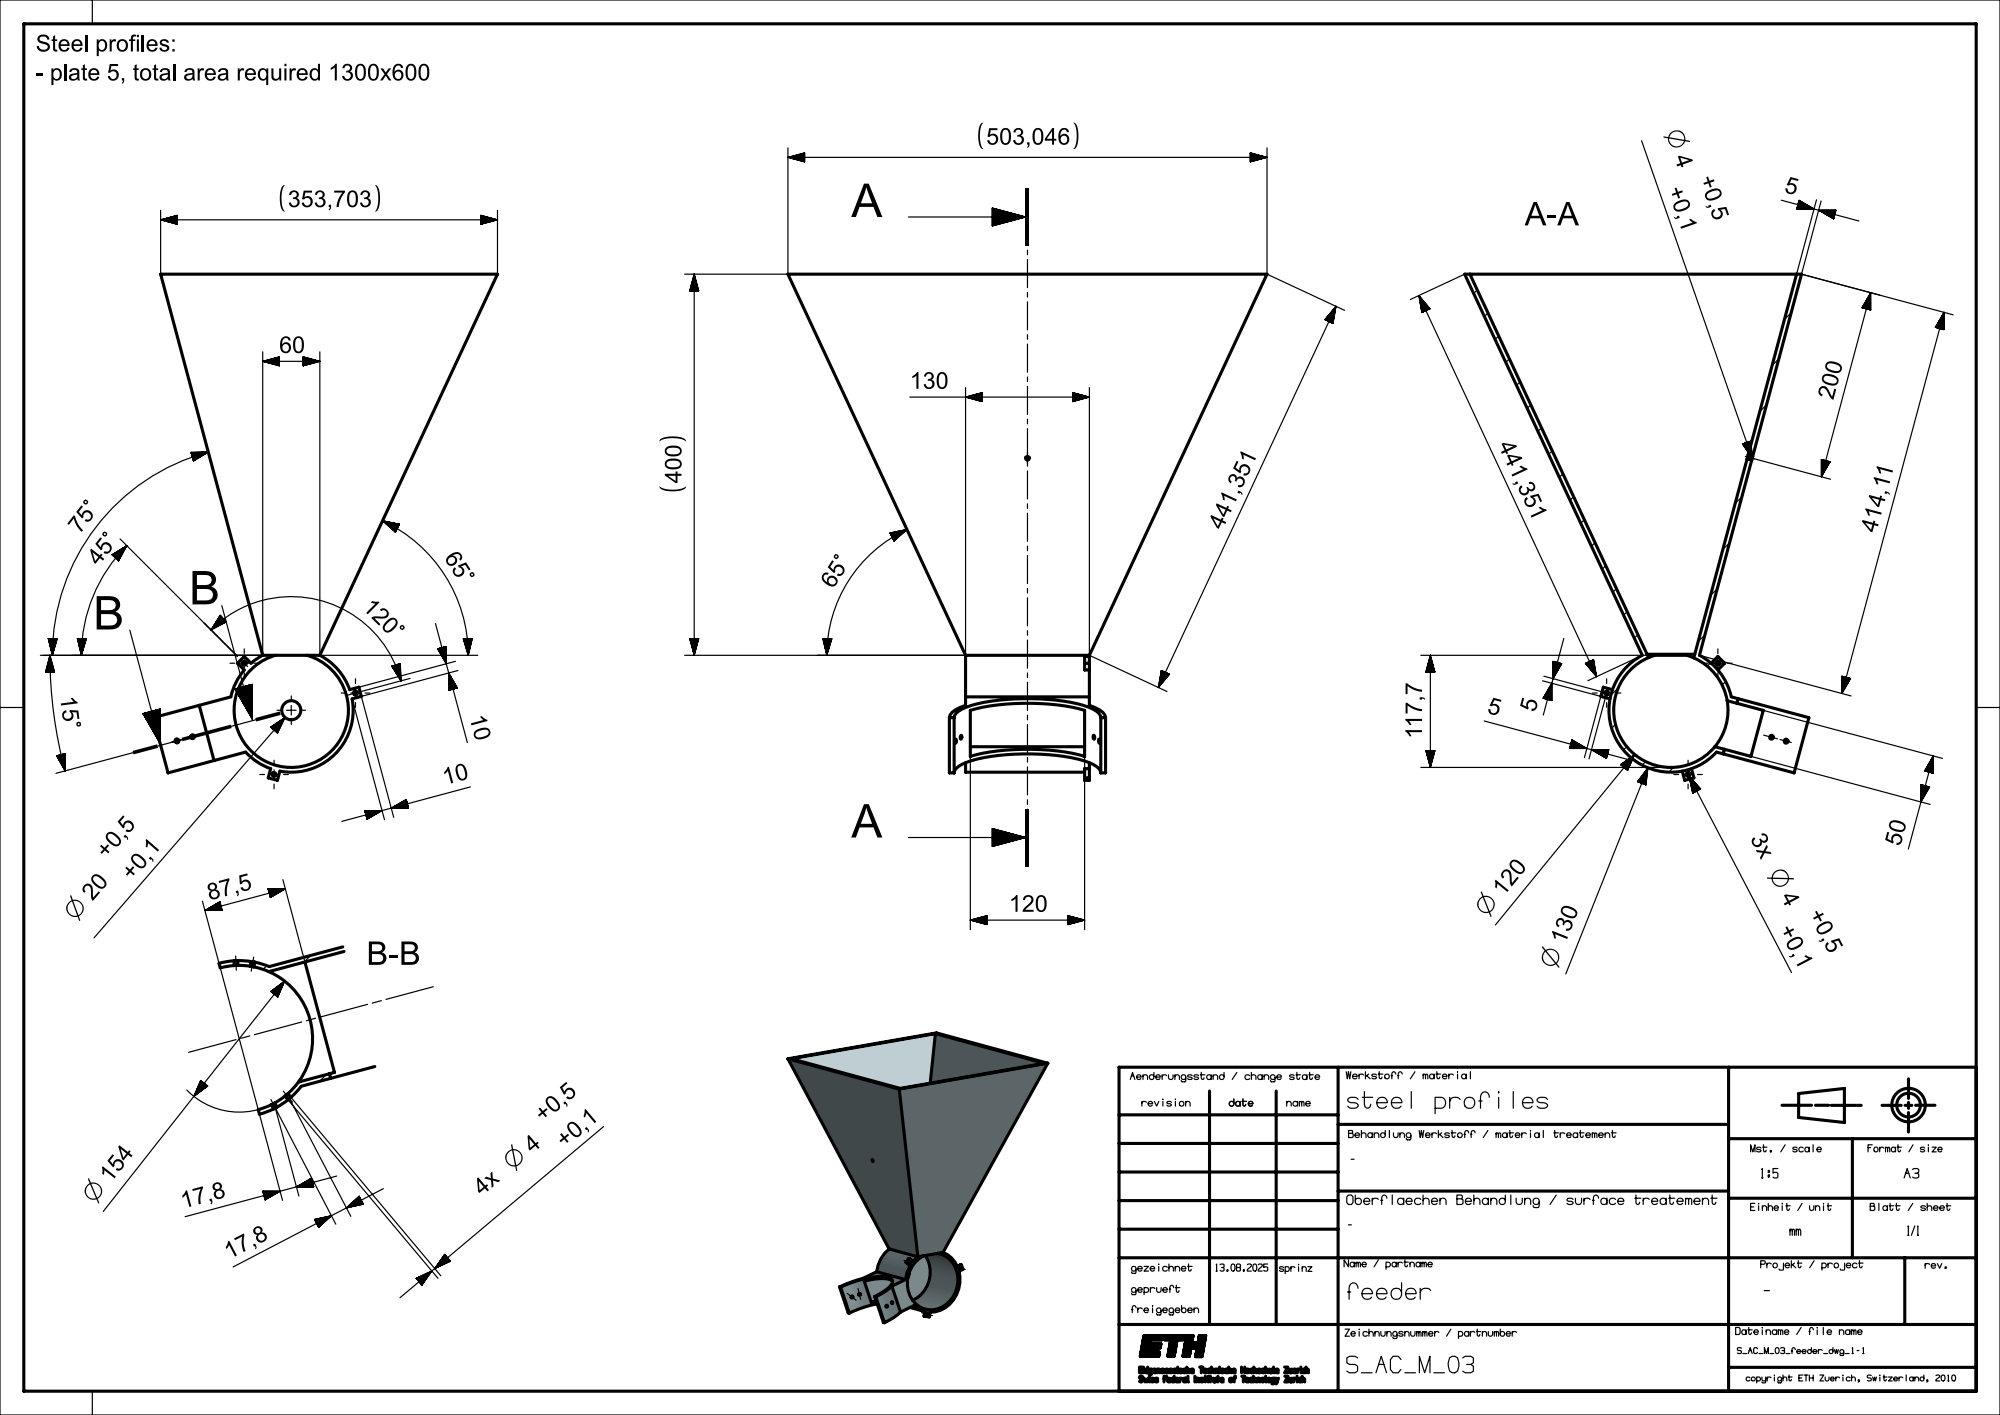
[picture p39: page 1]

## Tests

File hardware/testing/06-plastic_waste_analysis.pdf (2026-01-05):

July 2025 | 1 of 5

## Plastic waste analysis - Blantyre, Malawi

Testing Document

Version 1

Date:

- Start: 15.07.2025
- End: 17.07.2025

Contents

### General description and purpose

Purpose of test

To evaluate which separation steps should be implemented, the existing mixed plastic waste stored in Blantyre, Malawi must be analyzed.

Important criteria are: Present plastic types and flakes sizes.

The mixed plastic is stored in 1200 bags (estimate) of roughly 30 kg of plastic each.

Description of Test

First, samples are taken from the stored plastic. Since the waste in the bags in not homogeneous, the content of multiple bags is sampled. The bag is cut open and a small sample of flakes is gathered (choose different looking/colored flakes if possible). Then, the opening is sealed with duct tape and the bag as well as the sample are marked with an ID number to allow tracking. This process is repeated multiple times.

Once the samples are collected, the flakes are washed in a water-dish soap mixture and dried. Lastly, single flakes from each sample are scanned with the handheld NIR spectrometer (MicroPHAZIR PC). (https://www.physitek.fr/en/produit/microphazir-pc-handheld-nir-spectrometer/) Hereby, flakes exhibiting differences in color, size, or floating/sinking behavior in water are chosen and their plastic type is recorded. Limitations of the NIR spectrometer are the missing distinguishability between LDPE and HDPE (MicroPhazir only returns PE) and the inability to classify dark flakes.

Calculations

None.

Schedule of test with all steps required

1. Cut open a bag of mixed plastic waste.
2. Collect a small sample of flakes. Choose flakes of different color or size if applicable.
3. Close the opening with duct tape.
4. Mark the bag and the sample with its ID.
5. Repeat steps 1-4 for at least 5 bags at different locations in the pile. (Only bags that can be reached easily!)
6. Create a bath of water and dish soap.
7. Wash the flakes by hand one sample at a time.
8. Let the flakes dry.
9. For each sample, pick out flakes exhibiting differences in color, size, and/or floating/sinking behavior in water and scan the material with the NIR spectrometer.

Risk analysis

Potential risks associated with this test

The origin and content of the bags is unknown. Harmful dust particles could be present and dispersed in the air while sampling.

The bags have become very fragile over the long storing period and rip easily, possibly resulting in an avalanche like material stream.

Sharp objects could hide within the material. Small particles could get into the eyes.

Mitigation steps

A face mask (FFP3 recommended, minimum FFP2), safety glasses, and gloves are worn during the sampling. Furthermore, high boots are worn to improve stability and protect the ancles from falling material.

Only bags that are directly accessible without shifting around bags or climbing the pile are sampled.

Risks after taking mitigation steps

Ripping of bags and loosening of large amounts of plastic flakes is still possible. The sampling must be handled with care.

### Tools and devices required

Tool | Check-in tick
1x safety glasses | X
1x pair of gloves | X
1x face mask (min. FFP2, rec. FFP3) | X
1x pair of boots | X
1x key to storage | X
1x knife | X
Plastic bags (samples) | X
Duct tape | X
1x marker | X
Water to wash hands | X
Dish soap | X
Water | X
1x container for cleaning | X
1x MicroPHAZIR PC (https://www.physitek.fr/en/produit/microphazir-pc-handheld-nir-spectrometer/) | X
1x laptop | X
1x camera (phone) | X

### Testing Results

All pictures of the process and the results for each sample are available here. (https://drive.google.com/drive/folders/1OvgpcR5LIZ-oRcZbkWMCaT7RMeXIQzqC?usp=drive_link)

Only already open bags were sampled to limit the amount of plastic flakes spreading in the facility, since the pollution of the bags precluded resealing with duct tape.

Six bags were sampled. The extracted and washed flakes are shown in Figure 1.

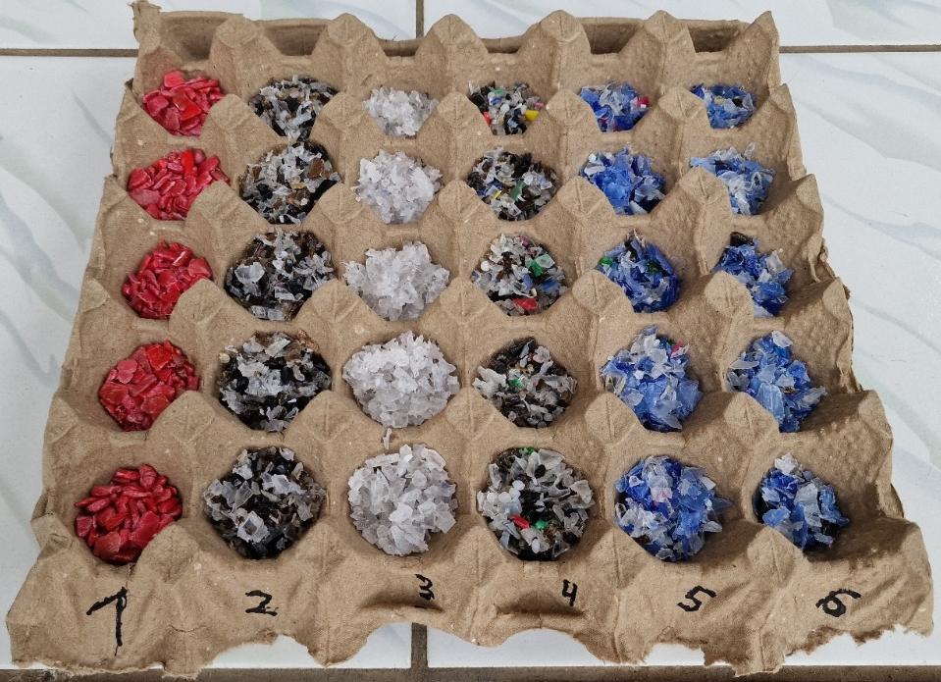
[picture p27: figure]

Figure 1: Plastic flake samples from the storage in Blantyre, Malawi.

ID | Observations | Material types (scanned) | Flake sizes [mm]
1 | (almost) fully floating; little debris on bottom; water almost clear; fibers of bag in sample | all PE (likely HDPE?) | 1x1 up to 23x4 & 19x9
2 | (almost) fully sinking; water little turbid; fibers of bag in sample | mostly PET, one PP (fibers of bag?), one Unidentified (black) | 1x1 up to 15x8, many <1 mm
3 | almost fully sinking; many very small pieces; water little turbid | all PET (including one foil piece) | 1x1 up to 29x6
4 | mostly sinking, some floating; water turbid; fibers (grass/bag?) in sample; twig in sample | float: mostly PP, two flakes PE (likely HDPE?) sink: mostly PET, one PE (likely HDPE?), one Unidentified (brown, maybe PET or PETG) | 1x2 up to 33x7
5 | fully sinking; relatively clear water | mostly PET, one PE (foil = LDPE?) | 2x2 up to 20x9
6 | (almost) fully sinking; small plastics floating (foils?); relatively clear water; small particles in water | mostly PET, one PP, one Unidentified (foil) | 1x2 up to 18x19, some smaller than holes in strainer

The scanned flakes from sample 4 are shown in Figure 2.

### Evaluation

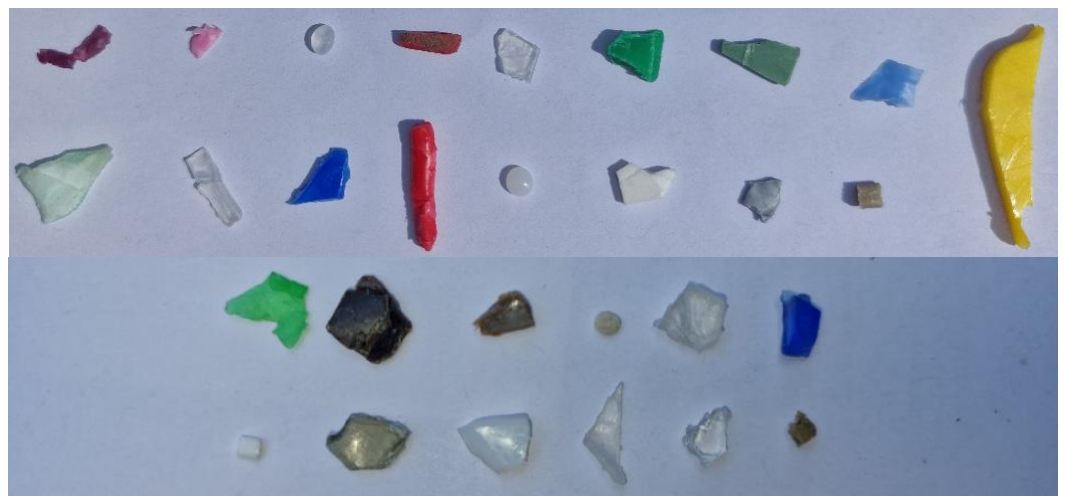
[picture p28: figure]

The plastic bags appear to already have undergone some sorting process. Except for sample 4, all bags show one predominant plastic type.

The identified plastic types present in the samples are: LDPE and/or HDPE, PP, PET. Unidentifiable flakes can be attributed to the dark color of the flake (black or brown) inhibiting the classification by the NIR spectrometer or an unknown or impure plastic type.
A wide range of flake sizes has been identified reaching from particles smaller than the strainer hole size up to 350 mm²

Due to the partially large pollution of the bags and the flakes, a washing step must precede the sorting.

Since bags located further back or towards the bottom of the pile could not be reached, the presence of other plastic types cannot be ruled out.

### Bibliography

Figure 2: The scanned flakes from sample 4. Top: floating in water; bottom: sinking in water.

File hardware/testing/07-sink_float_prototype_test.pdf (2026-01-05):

September 2025 | 1 of 13

## Sink-float prototype testing - Blantyre, Malawi

Testing Document

Version 1

Date:

- Start: 08.09.2025
- End: 12.10.2025

Contents

### General description and purpose

Purpose of test

Prototype tests fulfill two objectives:

1. To verify the satisfactory functionality of individual attributes of the machine. These tests are conducted during the manufacturing process to allow for timely modification in case of failure.
2. To validate the performance of the prototype, its functionality is tested after complete assembly.

In the case of the sink-float separation prototype, key features reviewed during the manufacturing are the tolerances between moving parts (trays and basins) and the leakage integrity of the basins. By ensuring that all trays fit in both basins in any orientation (horizontal rotation), convenient setup and operation is provided. The same applies to leak-proof vessels, which allow the prototype to be set up independently of a drainage in the location of use.

Once construction is complete, the prototype's operational capability in separating PET, HDPE, and PP is tested to evaluate the functionality of the design. This ensures that stakeholder requirements are met. Although the testing and sampling is done in Malawi, the evaluation of the separation purity is done in Germany using RTT’s flakeanalyser, (https://www.rtt-system.de/flakeanalyser-2.0.html) since no feasible in-line analysis method exists.

Description of Test

After the assembly of the basins and trays is finished (before applying the silicone), the trays are inserted into each of the two basins to scrutinize that the tolerances were met. This is done for each tray in all possible orientations, rotating the trays by 90° each time.
The leakage test is conducted after applying the silicone seal on the basins of the prototype. The basin with the cured silicone seals is placed on a dry surface and is filled with 50 liters of water. During the next five hours, the outside of the basin and the floor below is checked for any water drops.

Before the separation can be performed, the plastic flakes for the test must be prepared. For this, flakes from the stored plastic are used. Since the waste in the bags is not homogeneous, the content of multiple bags is taken to increase the mixture of different materials (use bags 1 and 4 from test 6 “Plastic waste analysis - Blantyre, Malawi”). (https://docs.google.com/document/d/1Yyw6Ywf_yFmdyPcIRzAQXuppkrJ1CTZU/edit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) A total of 200 kg is collected. Due to the poor integrity of the current bags in the storage, the flakes are transferred into new bags for transportation, each bag containing 50 kg of flakes. These flakes are then transported to Waste Advisers’ Innovation Hub where the sink-float separation prototype is set up.
To prepare the flakes for the separation process, they are washed with detergent and rinsed with clean water. Add roughly 50 kg of flakes to a plastic drum with water and detergent at a time, stir the mixture for 2 minutes and drain the content of the drum in the mesh-lined container (green) to strain the washed plastic flakes from the water. Rinse the flakes before transferring them to the storage container for mixed plastic (green). Repeat the process to clean all flakes. Take a 1 l sample of the washed, unsorted plastic flakes.
For the plastic separation, fill basin 1 with 30 l of water and add a little bit of detergent to reduce the surface tension. Place tray 1 in the basin and add 10 kg of plastic flakes. Depending on the fill level, height adjustment of the stirrer holder might be necessary. The stirrer should be positioned just below the water surface without touching the mesh of the tray. Then, use the stirrer to induce a current in the mixture to wet all plastic flakes well. After removing the stirrer from the basin and letting the flakes come to a rest, use the strainer to skim the floating flakes on the surface and transfer them into tray 2. When no more flakes float in the water, carefully lift the tray out of the water straining the sunken flakes. Transfer the sink fraction to the sorted PET container (orange) and take a 1 l sample. Fill basin 2 with 15 l of water and 15 l of ethanol. After mixing, take a sample of the solution with the measuring cylinder and test its ethanol content with the hydrometer. Adjust the mixture by adding ethanol or water to reach a solution at 50 vol %. Insert tray 2 with the float fraction from basin 1 into basin 2 and use the stirrer to wet all flakes. Remove the stirrer and, when the flakes are at rest, skim the floating flakes using the strainer and transfer the flakes to the sorted PP container (red). When the float fraction is removed, strain the remaining flakes by lifting tray 2 out of the solution and transfer the flakes to the sorted HDPE container (blue). Take a 1 l sample of the sorted PP and HDPE each.

After the testing is complete, the samples are transported to Germany. Here, the samples’ composition was analyzed at the K 2025 (“World's No. 1 Trade Fair for Plastics & Rubber”) in Duesseldorf, Germany, using the flakeanalyser (https://www.rtt-system.de/flakeanalyser-2.0.html) from RTT.
Inside the device, the flakes are recorded from different angles by numerous (optical) sensors. To identify different plastic types, primarily a near-infrared (NIR) sensor is used, whose measured spectrum is matched with the characteristic spectra of the different materials. The superposition of these images results in outputs for object count, area, and volume (all absolute and relative) differentiated by color and material type. The mass fraction, i.e. purity, of the different materials is derived from the volume measurements. Additionally, statistics of the grain sizes in the sample are returned.
During this process the following constraints influence the results:
- Due to their reduced reflection, black or dark-colored objects cannot be classified.
- LDPE and HDPE are indistinguishable from each other due to similar spectra.
- The object count must be considered carefully, since the internal computations “cut” large pieces to decrease the miscounting of contiguous flakes. For this purpose, a maximum grain size is defined in the software (here, it was set to 10 mm), which is based on experience and the average flake size within the sample.
- Large and light pieces (e.g., long fibers) pose a risk to the precise measurements as they are prone to shifting during the measurement, influencing the superposition of the different images negatively.

Calculations

None.

Schedule of test with all steps required

Fit test:

1. Insert tray 1 fully into basin 1 and ensure there is sufficient space between the parts.
2. Repeat step 1 three more times while rotating the tray by 90° in between.
3. Repeat steps 1 and 2 with basin 2.

4. Repeat steps 1-3 for tray 2 and tray 3.

Leakage Test:

1. Set up the basins on a dry, flat surface.
2. Fill the basins with 50 l of water.
3. Check the floor and the outside of the basin for water droplets during the next 5 hours.

Separation test:

1. Prepare the new storage bags for transferring of the flakes in the storage.
2. Select a bag and transfer the content to a new bag.
3. Close the bag and load onto car.
4. Repeat steps 2 and 3 for different bags/different plastic types until the target weight of 200 kg is reached (bags 1 and 4 from test 6).
5. Transport the test flakes to the Innovation Hub.
6. Add 50 kg of flakes to the plastic drum. Add water until the flakes are well wetted with enough room for the flakes to float freely. Add detergent to mix.
7. Stir with a stick for 2 min.
8. Carefully drain content of drum in batches through the green mesh-lined container.
9. Rinse flakes with water to clean off excess foam.
10. Transfer flakes to the storage container for mixed plastic flakes (green).
11. Repeat steps 6-10 until all flakes are washed.
12. Take 1 l sample of the washed, unsorted flakes.
13. Fill basin 1 with 30 l of water and add 15 g of detergent.
14. Place tray 1 in the basin.
15. Fill the tray with 10 l of the mixed plastic.
16. Adjust the stirrer height, so that the stirrer head is positioned just below the water surface without touching the mesh of the tray.
17. Use the stirrer to stir the mixture to wet all flakes properly (5 min).
18. Remove the stirrer and let the flakes settle until all vertical movement has stopped.
19. Use the strainer to skim the float fraction. Transfer the flakes to tray 2.
20. When no floating plastic remains, lift tray 1 with the remaining sink fraction out of the basin, draining the water in the process. Transfer the flakes to the sorted PET container (orange).
21. (If not enough sink or float fraction for sample repeat steps 14 – 20.)
22. Take 1 l sample of the sorted PET from the PET container.
23. Fill basin 2 with 15 l of water and 15 l of ethanol and mix.
24. Verify the ethanol content in the solution of 50 vol % with the hydrometer. Adjust if needed.
25. Place tray 2 with the float fraction from basin 1 in basin 2.
26. Repeat steps 16-18.
27. Use the strainer to remove the float fraction from the basin and transfer them to the sorted PP container (red).
28. When no floating plastic remains, lift tray 2 with the remaining sink fraction out of the basin, draining the water in the process.
29. Transfer the sink fraction to the sorted HDPE container (blue).

30. Take 1 l sample of the sorted HDPE from the HDPE container.
31. Take 1 l sample of the sorted PP from the PP container.

Analysis of sample composition:

1. Follow the instructions by RTT.

Risk analysis

Potential risks associated with this test

The origin and content of the bags is unknown. Harmful dust particles could be present and dispersed in the air while sampling.

The bags have become very fragile over the long storing period and rip easily, possibly resulting in an avalanche like material stream.

Sharp objects could hide within the material. Small particles could get into the eyes.

Ethanol is highly flammable in liquid and vapor form and can cause serious eye irritation.

Mitigation steps

A face mask (FFP3 recommended, minimum FFP2), safety glasses, and gloves are worn during the sampling. Furthermore, high boots are worn to improve stability and protect the ancles from falling material. Additionally, acquiring the flakes is handled by two people.

The tests including ethanol are done in a ventilated area and possible sources of fire are removed.

Safety glasses are worn at any time during the testing with ethanol.

Risks after taking mitigation steps

Ripping of bags and loosening of large amounts of plastic flakes is still possible. The sampling must be handled with care.

### Tools and devices required

Tool | Check-in tick
2x safety glasses | X
2x pair of gloves | X
2x face mask (min. FFP2, rec. FFP3) | X
2x pair of boots | X
1x key to storage | X
1x knife | X
4x new storage plastic bags | X

Duct tape | X
Dish soap | X
Water | X
1x large plastic drum for cleaning | X
1x stirrer stick | X
1x mesh-lined container | X
4x storage container for mixed plastic flakes and sorted plastics | X
Sink-float separation prototype | X
1 l measuring cup | X
1x hydrometer | X
2x strainer | X
20 l of ethanol | X
4x 1 l sample bags | X
1x laptop | X
1x phone (camera and watch) | X

### Testing Results

All recordings and pictures of the process are available here. (https://drive.google.com/drive/folders/18txpXET8JIJTCcASMgkbjnbMdMYlGEbn?usp=drive_link)

Fit Test – 08.09.2025

All trays could be inserted with ease in all orientations for both basins.

Leakage Test – 08.09.2025

No leakage could be detected during the five hour test time.

Addendum (22.9.25): After working on the prototype over the weekend at home outside, the silicone seal of one basin came off on two edges, possibly due to sunlight and/or heat. Due to time constraints, the seal cannot be redone before the prototype functionality testing (three days curing time). Instead, the seals were covered with duct tape to keep the silicone joints in place and reduce the friction between the edges of the trays and the silicone joints for the full prototype test. After the tests, the seal is renewed.

Functionality Test – 23.-24.09.2025

Plastic flakes acquisition from storage

Roughly 15 % of the bags in the storage were gone, including the bags sampled in test 6. It was unknown that the plastic is still used by MTEC, a company cooperating with Waste Advisers, for their projects.

The majority of remaining plastic (in accessible bags) was PET, while only half a bag of HDPE was found (maybe other material somewhere in the pile). Only two bags in total were collected and transported to the Innovation Hub for testing, since bringing more relatively pure PET did not add value to the test.

Other bags in storage not taken to testing also included large pieces of plastic foil.

Flake washing

Contamination found during washing: screw, metal pieces, ceramic tile pieces, charcoal, cement pieces (see Figure 1).

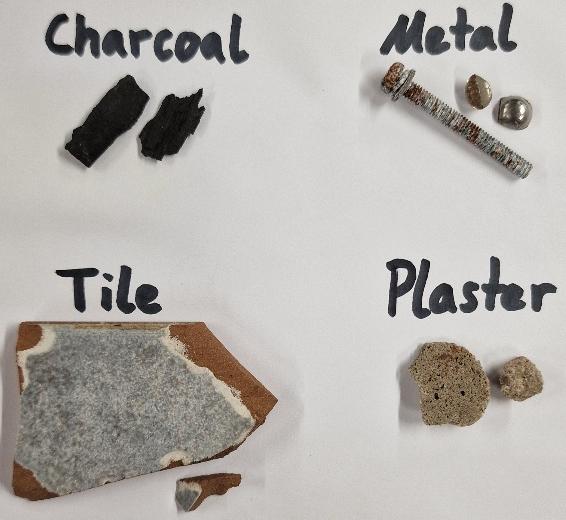
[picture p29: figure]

Figure 1: Contamination found with plastic flakes during washing.

Plastic separation by sink-float prototype

In contrast to the flake behavior observed in test 1 “Sink-float separation - Proof of concept” (https://docs.google.com/document/d/1ngdAf8as1NAp7tlwLvzU2yW88cCANNGC/edit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) where work was required to wet the flakes, a large amount of flakes added to basin 1 in the first separation step immediately sank to the bottom, including flakes of a density lower than water that were pulled down by the surplus of PET flakes. This is likely a consequence of the preceding washing step, from which the flakes were still wet at the time of testing. Thus, two different separation procedures were tested:

1. One long period of stirring the flakes followed by skimming the floating fraction off the surface – suited for wetting hydrophobic plastic flakes.
2. Repeated execution of the stirring and skimming step. Here, a ladle was used instead of the stirrer for easier switching between the steps.

Both procedures were sampled and analyzed, resulting in a total of five samples. For the second sink-float process in basin 2, the second method was used as well, since its superiority for the present case was visually apparent.

Sample | Description | Ideal outcome
Sample 1 | Basin 1, sink fraction – one long period of stirring | Pure PET
Sample 2 | Basin 1, sink fraction – stirring and skimming multiple times | Pure PET
Sample 3 | Basin 2, float fraction – stirring and skimming multiple times | Pure PP
Sample 4 | Basin 2, sink fraction – stirring and skimming multiple times | Pure HDPE
Sample 5 | Initial mixed plastic flakes | –

Sample Composition Analysis – 12.10.2025

The raw results’ data can be found here. (https://drive.google.com/drive/folders/12AAGPWsHHukij2c771EeJNLpbahLKOfW?usp=drive_link)

For the analysis, the raw data underwent a series of data processing steps:

- Since the distinction between different colors of PE and PP is not significant, the individual measurements are summed up.
- ABS, PA, PC, and Other Plastics are grouped into Other Plastics due to the low number of detected flakes.
- The result is ordered to suit the topic of the thesis with the most important measurements on top.
- Lastly, the column mass [g] is removed since this value is not measured but calculated by the flakeanalyser based on the total weight of the sample. This value is not measured internally but entered by the user prior to the scan. An arbitrary value (123 g) was used in this case. Thus, the results are not significant.
- For clarity, only the most important values (mass [%], volume [%], and object count) are displayed in the derived results below.

The values for the material “Cell” cover cellulose-based materials such as paper or leaves. If flakes return no sufficient congruence to any entry in the database, it could either be due to their dark or black color – assigned to the material “Black” – or because no characteristic spectrum was recorded and saved for this material which is included as “Not identifiable”.

Sample 1

Basin 1, sink fraction – one long period of stirring
Ideal outcome: pure PET
Material | Mass [%] | Volume [%] | Object count []
PP | 0.56 | 0.81 | 98
PE | 6.90 | 9.74 | 680
PET | 89.87 | 86.44 | 10,314
PS | 0.00 | 0.00 | 1
PVC | 0.45 | 0.43 | 49
Other Plastics | 0.00 | 0.00 | 0
Metal | 0.68 | 0.45 | 41
Cell | 0.13 | 0.24 | 24
Not identifiable | 0.00 | 0.00 | 0
Black | 1.42 | 1.89 | 154

Sample 2

Basin 1, sink fraction – stirring and skimming multiple times
Ideal outcome: pure PET
Material | Mass [%] | Volume [%] | Object count []
PP | 0.21 | 0.32 | 59
PE | 0.35 | 0.51 | 83
PET | 96.55 | 95.84 | 13,336
PS | 0.00 | 0.00 | 0
PVC | 0.76 | 0.75 | 83
Other Plastics | 0.00 | 0.00 | 0
Metal | 0.57 | 0.39 | 58
Cell | 0.10 | 0.19 | 37
Not identifiable | 0.00 | 0.00 | 0
Black | 1.46 | 2.00 | 183

Sample 3

Basin 2, float fraction – stirring and skimming multiple times
Ideal outcome: pure PP
Material | Mass [%] | Volume [%] | Object count []
PP | 69.76 | 70.46 | 5,641
PE | 29.93 | 29.26 | 2,975
PET | 0.03 | 0.02 | 37
PS | 0.00 | 0.00 | 2
PVC | 0.04 | 0.03 | 14
Other Plastics | 0.00 | 0.00 | 5
Metal | 0.00 | 0.00 | 0
Cell | 0.02 | 0.03 | 32
Not identifiable | 0.00 | 0.00 | 0
Black | 0.20 | 0.19 | 18

Sample 4

Basin 2, sink fraction – stirring and skimming multiple times
Ideal outcome: pure HDPE
Material | Mass [%] | Volume [%] | Object count []
PP | 0.10 | 0.11 | 16
PE | 99.77 | 99.81 | 7,411
PET | 0.10 | 0.07 | 8
PS | 0.00 | 0.00 | 0
PVC | 0.02 | 0.01 | 3
Other Plastics | 0.00 | 0.00 | 0
Metal | 0.00 | 0.00 | 0
Cell | 0.00 | 0.00 | 2
Not identifiable | 0.00 | 0.00 | 0
Black | 0.01 | 0.01 | 2

Sample 5

Initial mixed plastic flakes

Material | Mass [%] | Volume [%] | Object count []
PP | 2.58 | 3.52 | 406
PE | 19.97 | 26.37 | 2,402
PET | 75.21 | 67.64 | 11,390
PS | 0.00 | 0.00 | 1
PVC | 0.65 | 0.58 | 74
Other Plastics | 0.00 | 0.00 | 2
Metal | 0.23 | 0.14 | 31
Cell | 0.11 | 0.20 | 55
Not identifiable | 0.00 | 0.00 | 0
Black | 1.25 | 1.55 | 137

### Evaluation

The successful fit and leakage tests allowed to proceed with the manufacturing.

Although enough HDPE and PP flakes were available for the prototype testing, the remaining plastic bags in the storage contain PET with high purity. Despite not being designed for this case, the prototype can still be used to improve the purity further by removing remaining plastics like LDPE, HDPE, and PP in the water basin.

Pollutants such as tile or metal pieces found in the plastic are not addressed by the prototype. Large pieces can be picked out by hand, whereas an additional cleaning step using magnets or eddy currents could facilitate the removal of metal. Depending on the intended use of the separated flakes, this must be addressed in a follow-up project.

When evaluating the purity results of sample 1 and sample 2, the assumption from the visual assessment was confirmed: with a purity of 96.55 %, the process applied to sample 2 not only exceeds the purity of sample 1 but also meets the prototype's target of at least 95 %. Thus, repeated stirring and skimming is recommended for the present conditions in order to obtain PET at the desired purity.

Sample 3 exposed an insufficient outcome in PP separation. Possible explanations are a distortion of the result due to long PP fibers or the influence of LDPE in the initial plastic mix. The density of LDPE (0.924 g/cm³
) lies right within the targeted separation medium density (0.9265 to 0.9227 g/cm³
, see test 4 “Light sink float separation - Proof of concept”). (https://docs.google.com/document/d/1Ve_f0ElzmN9-XGNl7_ycVKqIRGRsCqc1/edit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) Only small variations in the chemical composition of the medium or ambient temperature can manipulate the allocation of LDPE to the float or sink fraction. Since the overall content of PP in the initial plastic mix is relatively small with only 2.58 % (see Sample 5), low quantities of LDPE assigned to the float fraction can strongly sway the outcome. Consequently, the PP can either be discarded or purified in an additional process

step.
Surprising are the presence of PVC and PET flakes in sample 3, since their densities are much higher than that of the separation medium. Possible explanations are multilayered plastics of different types or the interlocking of different flakes.

The highest purity of 99.77 % was recorded for PE (mostly HDPE) in sample 4, with only 29 to 31 out of 7442 flakes being assigned to the sink fraction incorrectly. This clearly exceeds the purity target and facilitates the reuse of the material. Depending on the designated recycling application, a possible presence of LDPE flakes in the material must be accounted for.

Despite reaching the purity goals for PET and HDPE, impurities detected in the samples can reduce reusability of the plastics. While not identified during test 6 “Plastic waste analysis - Blantyre, Malawi”), (https://docs.google.com/document/d/1Yyw6Ywf_yFmdyPcIRzAQXuppkrJ1CTZU/edit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) even small quantities of PVC can have negative impacts on the mechanical and optical properties of the recycled product (ASG, 2013). Depending on the intended use, this must be addressed in future work.

Remarks:

- Since black or dark flakes cannot be assigned by the flakeanalyser, the real results likely deviate slightly from the results presented above. However, these flakes are represented in a separate row, which leads to a conservative estimate of the result. The real purity value is equal to or better than the measured value.
- Classification by comparing spectra is an estimate, since the measured can deviate from the material’s characteristic spectrum (see the RTT lab report). (https://drive.google.com/file/d/1eIERUccihECwYb2M2cVT1r_b1FWTPM6k/view?usp=drive_link) However, the specific decision-making process behind the flakeanalyser is unknown. Thus, an ideal identification of materials is assumed as no statistical analysis is possible.

### Bibliography

ASG. (2013, June 5). PVC in PET Bottle Recycling. PET Bottle Washing Line | ASG Plastic

Recycling Machine. https://www.petbottlewashingline.com/pvc-in-pet-bottle-recycling/

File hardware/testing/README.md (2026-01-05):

---
README for `./hardware/testing`
---

Numerous tests were conducted during the course of the thesis. An overview of the conducted tests is given in the table below.
To allow reproduction, the detailed documentation including testing description, schedule, tools, results, and evaluation are provided in this directory.

Data gathered and processed during these tests is provided in the directory `./data`. See the associated `README.md` file for further information.
Furthermore, all media recorded during the tests is accessible in the directory `./media/testing`.

| Test document | Description | Date | Geographic location |
| --- | --- | --- | --- |
| `01-sink_float_sep-proof_of_concept.pdf` | Small-scale proof-of-concept test | 2025-06-06 - 2025-06-16 | ETH CLA, Tannenstrasse 3, 8092 Zurich, Switzerland |
| `02-hdp_sep-proof_of_concept.pdf` | Small-scale proof-of-concept test | 2025-06-17 - 2025-06-18 | ETH CLA, Tannenstrasse 3, 8092 Zurich, Switzerland |
| `03-ldp_sep-proof_of_concept.pdf` | Small-scale proof-of-concept test | 2025-06-19 | ETH CLA, Tannenstrasse 3, 8092 Zurich, Switzerland |
| `04-light_sink_float_sep-proof_of_concept.pdf` | Small-scale proof-of-concept test | 2025-07-03 - 2025-07-07 | ETH CLA, Tannenstrasse 3, 8092 Zurich, Switzerland |
| `05-water_quality_test.pdf` | Analysis of water used for tests which possibly influences the results | 2025-07-01 - 2025-09-25 | ETH CLA, Tannenstrasse 3, 8092 Zurich, Switzerland & WASTE Advisers Innovation Hub, Chigumula, Malawi (15°53'08.5"S 35°03'49.5"E) |
| `06-plastic_waste_analysis.pdf` | Analysis of the mixed plastic waste stored by WASTE Advisers | 2025-07-15 - 2025-07-17 | WASTE Advisers Plastic Storage, Blantyre, Malawi (15°48'35.6"S 35°02'39.4"E) |
| `07-RTT_lab_report_detail.pdf` | Detailed flake analysis by RTT augmenting the `07-sink_float_prototype_test.pdf` | 2025-11-05 | RTT System GmbH, Hirschfelder Ring 9a, 02763 Zittau, Germany |
| `07-sink_float_prototype_test.pdf` | Sink-float separator prototype test | 2025-09-08 - 2025-10-12 | WASTE Advisers Innovation Hub, Chigumula, Malawi (15°53'08.5"S 35°03'49.5"E) & Messe Duesseldorf, Stockumer Kirchstraße 61, 40474 Duesseldorf, Germany |

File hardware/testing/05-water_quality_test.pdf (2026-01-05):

July 2025 | 1 of 7

## Water quality testing

Testing Document

Version 1

Date:

- Start: 01.07.2025
- End: 25.09.2025

Contents

### General description and purpose

Purpose of test

The sink-float separation is likely one of the methods used for the separation of plastic types in Blantyre. In the case that the results acquired during small scale tests in Zurich are not reproducible during the field work in Malawi, possible influence factors must be examined. For this, the water is analyzed, first in Zurich, then at Waste Adviser’s Innovation Hub in Blantyre.

Measured values of the water are:

- pH value
- (Total) water hardness
- Free chlorine content
- Iron content
- Copper content
- Lead content
- Nitrate content
- Nitrite content
- Potassium monopersulfate content
- Total chlorine content
- Fluoride content
- Cyanuric acid content
- Ammonium chloride content
- Bromines content
- Total alkalinity
- Carbonates content

These values can serve for comparison during the analysis.

Description of Test

For the pH testing, the LLG-pH Meter 5 (https://shop.llg-labware.com/info6022llg-ph-meter-5_lang_de.htm?UID=550068664ce6000000000000) is used. Furthermore, a water hardness test set (https://agualeve.de/products/wasserhaerte-test-15ml) and a 16 in 1 water quality tester (https://www.bmut.de/product/100x-16in1-trinkwasser-teststreifen-fuer-leitungswasser-wasserqualitaet-analyse-gesamthaerte-eisen-blei-kupfer-nitrat-etc/) is acquired. For all measurements, tap water from the same source as for the tests is used. The test procedures follow the instructions included with each product.

Calculations

Table 1: Water hardness unit conversion (“Wasserhärte messen,” n.d.)

mol/m³ | | <0.7 | >1.0 | >1.8 | >2.7 | >3.6 | >4.5
°d | German degree of hardness | 0 | 5 | 10 | 15 | 20 | 25
°f | French degree of hardness | 0 | 9 | 18 | 27 | 36 | 45
°e | English degree of hardness | 0 | 6.25 | 12.5 | 18.75 | 25 | 31.25

Schedule of test with all steps required

1. Read the instructions for all three test devices.
2. To obtain the test water let the water run until a constant temperature is reached. Then, fill two beakers for the tests.
3. Conduct the pH measurement with the pH meter by following the instructions of the device.
4. Set up the camera for the hardness test.
5. Conduct the water hardness measurement by following the tools instructions.
6. Conduct the water quality test by following its instructions.
7. Record a photo of the result.
8. Repeat the steps for all water sources used for testing.

Risk analysis

Potential risks associated with this test

None.

Mitigation steps

Safety glasses are worn during the whole process.

Risks after taking mitigation steps

None.

### Tools and devices required

Tool | Check-in tick
1x safety glasses | X
Paper towels | X
1x laptop | X
1x camera (phone) | X
1x timer (laptop or phone can be used) | X
1x pH meter | X
1x water hardness test set (https://agualeve.de/products/wasserhaerte-test-15ml) | X
1x 16 in 1 water quality tester (https://www.bmut.de/product/100x-16in1-trinkwasser-teststreifen-fuer-leitungswasser-wasserqualitaet-analyse-gesamthaerte-eisen-blei-kupfer-nitrat-etc/) | X
2x beaker | X
0.8 l tap water | X

### Testing Results

All recordings and pictures of the process and the results for each sample are available here. (https://drive.google.com/drive/folders/1xhSZv94cGWVHRAnn9Qa0YwOuMybGzckW?usp=drive_link)

In Blantyre, two different water sources are available at the Innovation hub.

Zurich

Test: 01.07.2025

pH meter not functional → pH test strips used instead

Water sampling time: 15:09

Test | Result | Observation
pH [] | 6 (repeated test with new pH meter on July 4, 2025: pH = 7.0 to 7.6 continuously growing)

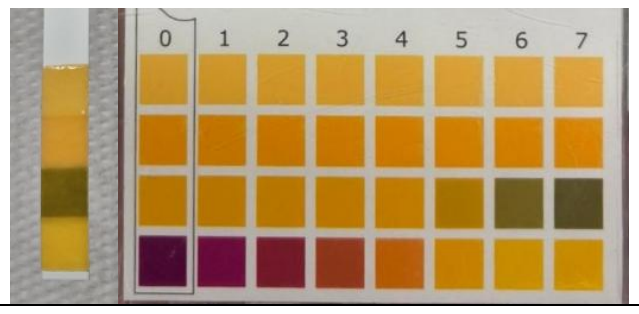
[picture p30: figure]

Water hardness [°dH] | 10 | 10 drops

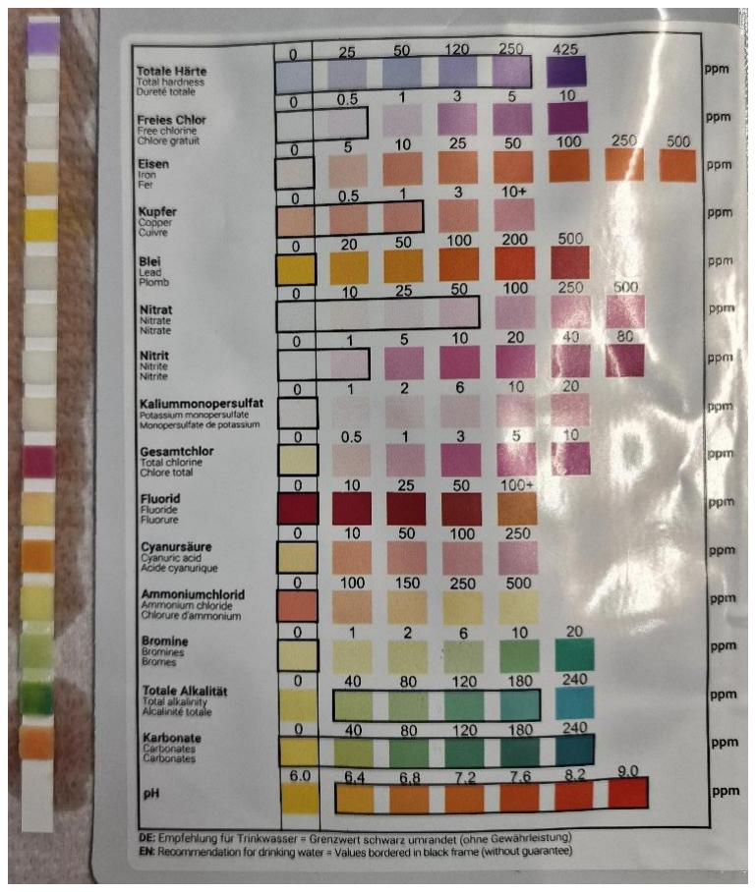
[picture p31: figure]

### 16 in 1

test
[ppm]

Total hardness: 250 – 425

Free chlorine: 0

Iron: 0

Copper: 0

Lead: 0

Nitrate: 0 – 10

Nitrite: 0

Potassium monopersulfate: 0 – 1

Total chlorine: 0

Fluoride: 0

Cyanuric acid: 0

Ammonium chloride: 0

Bromines: 1

Total alkalinity: 40

Carbonates: 120

pH: 6.8
Blantyre

Test 1: 23.09.2025 – Innovation Hub outside reservoir pH meter not available → pH test strips used instead

Water sampling time: 13:07 (test conducted 25.09.2025)

pH [] | 5 – 6

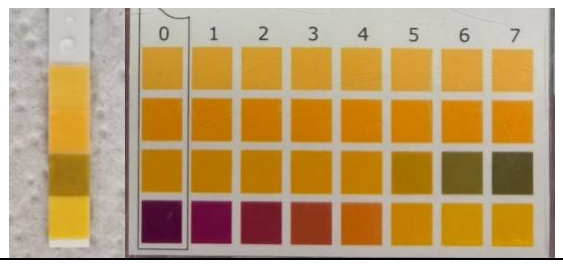
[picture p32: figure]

Water hardness [°dH] | 7 | 7 drops

### 16 in 1

test
[ppm]

Total hardness: 250

Free chlorine: 0

Iron: 0

Copper: 0

Lead: 0

Nitrate: 50 – 100

Nitrite: 0

Potassium monopersulfate: 0

Total chlorine: 0

Fluoride: 0

Cyanuric acid: 0

Ammonium chloride: 0 – 100

Bromines: 1

Total alkalinity: 40

Carbonates: 40 – 80

pH: 6.4

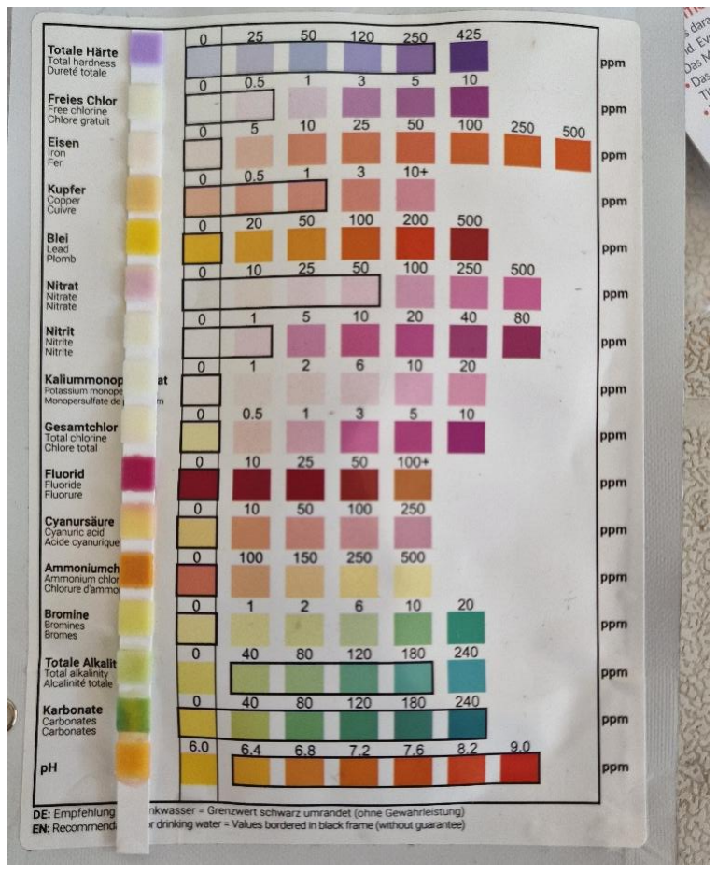
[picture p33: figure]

Test 2: 24.09.2025 – Innovation Hub inside tab

pH meter not available → pH test strips used instead

Water sampling time: 11:30 (test conducted 25.09.2025)

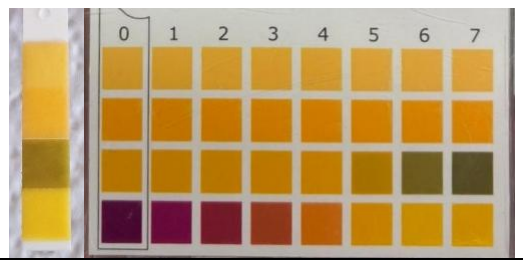
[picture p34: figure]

pH [] 5 – 6

Water
hardness
[°dH]
6 | 6 drops

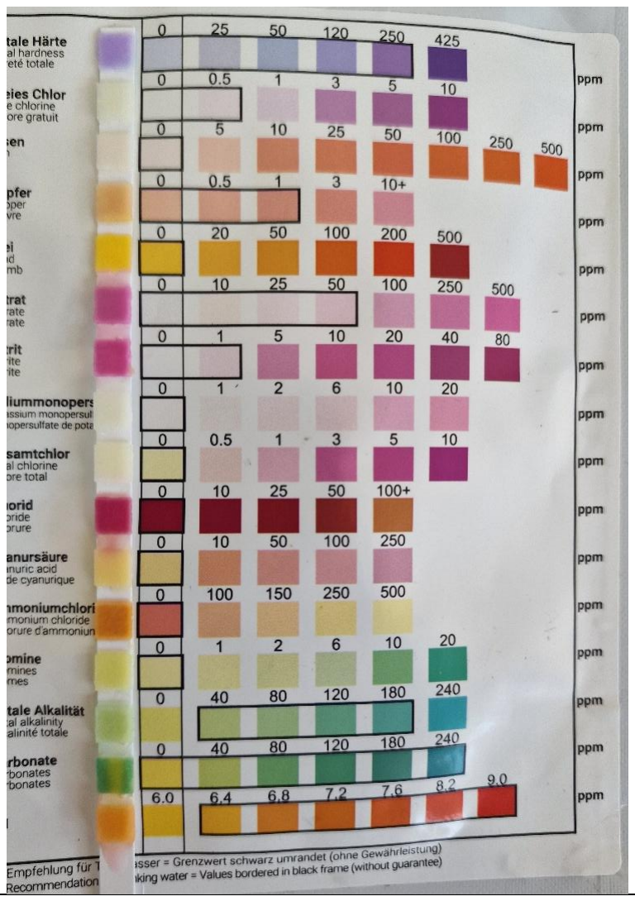
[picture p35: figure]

### 16 in 1

test
[ppm]

Total hardness: 250

Free chlorine: 0

Iron: 0

Copper: 0

Lead: 0

Nitrate: 500

Nitrite: 10

Potassium monopersulfate: 0

Total chlorine: 0

Fluoride: 0

Cyanuric acid: 0

Ammonium chloride: 0 – 100

Bromines: 1

Total alkalinity: 40

Carbonates: 40 – 80

pH: 6.8

### Evaluation

The pH value is fairly similar between all measurements.

The hardness measurements returned higher values in Zurich than for the two measurements in Blantyre. As described in the explanations provided with the 16 in 1 test set (see Figure 1), a higher lime concentration reduces the solubility of soap in water. This could necessitate a larger amount of detergent in Zurich compared to Blantyre.

With the 16 in 1 test, much higher-than-normal nitrite and nitrate concentrations were detected in the water from the inside tab at Waste Adviser’s Innovation Hub, while the nitrate value for the outside reservoir were only slightly above the recommended values for drinking water in Germany. This can be contributed to the high usage of fertilizer in Malawi’s agriculture. The test in Zurich recorded nitrite and nitrate values well within these recommendations.
All other values were similar within the different water samples and mostly in a recommended range.

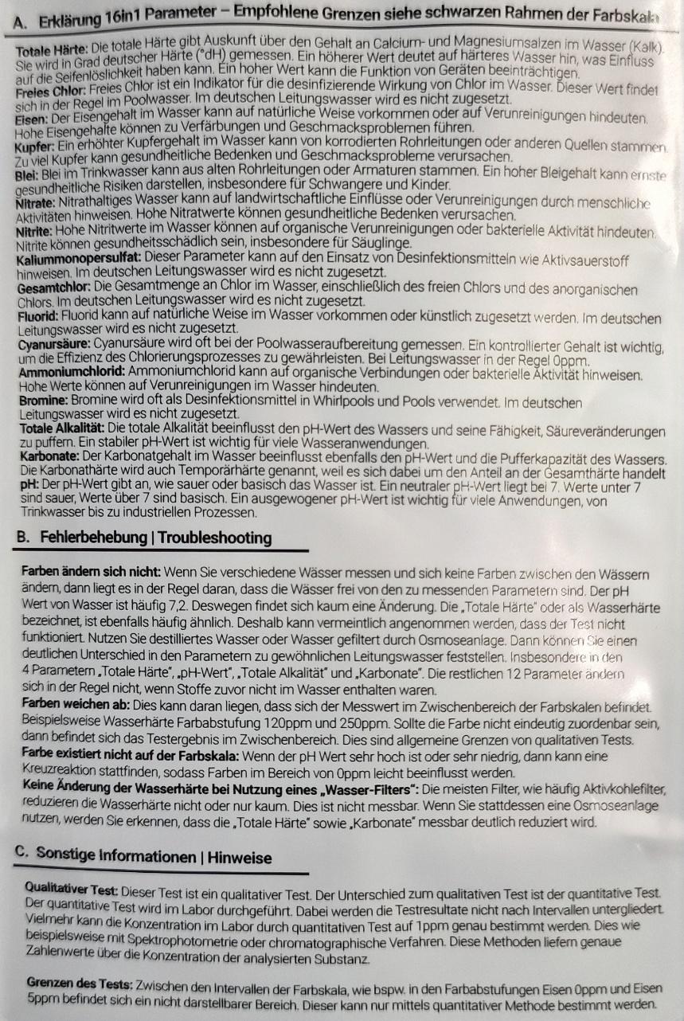
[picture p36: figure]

Figure 1: Explanations, troubleshooting, and other information enclosed with the 16 in 1 water quality tester.

### Bibliography

Wasserhärte messen. (n.d.). Wasserhärte Schweiz | Bögli AG Wasseraufbereitung. Retrieved June 27,

2025, from https://wasserhaerteschweiz.ch/messen/

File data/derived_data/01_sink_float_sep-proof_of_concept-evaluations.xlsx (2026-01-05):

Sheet: evaluation
id | sep_sol_id | stir_method_id | sep_sol | stir_method | run | in_PP_g | in_LDPE_g | in_HDPE_g | in_PS_g | in_PET_g | in_PVC_g | in_tot_g | float_right_g | float_PS_g | float_PET_g | float_PVC_g | sink_PP_g | sink_LDPE_g | sink_HDPE_g | sink_right_g | purity_float | purity_sink | combined_purity
9 | b | 3 | tap water + detergent | vigorous (turbulent) | 1 | 0.6 | 0.2 | 2.0 | 2.4 | 2.7 | 1.7 | 9.4 | 2.61 | 0 | 0 | 0 | 0 | 0.003 | 0 | 6.7 | 100.00% | 99.96% | 99.98%
8 | b | 2 | tap water + detergent | slow (300rpm) | 1 | 0.6 | 0.2 | 2.0 | 2.4 | 2.7 | 1.7 | 9.4 | 2.91 | 0.0001 | 0 | 0 | 0 | 0.01 | 0 | 6.43 | 100.00% | 99.84% | 99.92%
15 | d | 3 | tap water + NaCl | vigorous (turbulent) | 1 | 0.6 | 0.2 | 2.0 | 2.4 | 2.7 | 1.7 | 9.3 | 2.79 | 0.06 | 0 | 0 | 0 | 0.01 | 0 | 6.41 | 97.89% | 99.84% | 98.87%
11 | c | 2 | tap water + CaCl2 | slow (300rpm) | 1 | 0.6 | 0.2 | 2.0 | 2.4 | 2.7 | 1.7 | 9.9 | 3.3 | 0.14 | 0.02 | 0 | 0 | 0 | 0 | 6.36 | 95.38% | 100.00% | 97.69%
14 | d | 2 | tap water + NaCl | slow (300rpm) | 1 | 0.6 | 0.2 | 2.0 | 2.4 | 2.7 | 1.7 | 9.4 | 2.62 | 0.05 | 0.08 | 0 | 0 | 0 | 0 | 6.45 | 95.27% | 100.00% | 97.64%
12 | c | 3 | tap water + CaCl2 | vigorous (turbulent) | 1 | 0.6 | 0.2 | 2.0 | 2.4 | 2.7 | 1.7 | 9.3 | 2.68 | 0.11 | 0.03 | 0 | 0 | 0.003 | 0 | 6.54 | 95.04% | 99.95% | 97.49%
2 | a | 2 | tap water | slow (300rpm) | 1 | 0.6 | 0.2 | 2.0 | 2.4 | 2.7 | 1.7 | 9.4 | 2.72 | 0.12 | 0.03 | 0 | 0 | 0.01 | 0 | 6.58 | 94.77% | 99.85% | 97.31%
3 | a | 3 | tap water | vigorous (turbulent) | 1 | 0.6 | 0.2 | 2.0 | 2.4 | 2.7 | 1.7 | 9.2 | 2.59 | 0.19 | 0 | 0 | 0 | 0.003 | 0 | 6.39 | 93.17% | 99.95% | 96.56%
6 | a | 3 | tap water | vigorous (turbulent) | 2 | 0.6 | 0.2 | 2.0 | 2.4 | 2.7 | 1.7 | 9.2 | 2.63 | 0.27 | 0.01 | 0 | 0 | 0.001 | 0 | 6.28 | 90.38% | 99.98% | 95.18%
5 | a | 2 | tap water | slow (300rpm) | 2 | 0.6 | 0.2 | 2.0 | 2.4 | 2.7 | 1.7 | 9.4 | 2.63 | 0.21 | 0.07 | 0 | 0 | 0.01 | 0 | 6.45 | 90.38% | 99.85% | 95.11%
7 | b | 1 | tap water + detergent | none | 1 | 0.6 | 0.2 | 2.0 | 2.4 | 2.7 | 1.7 | 10.0 | 3.36 | 0.54 | 0.21 | 0 | 0 | 0.0001 | 0 | 5.88 | 81.75% | 100.00% | 90.88%
13 | d | 1 | tap water + NaCl | none | 1 | 0.6 | 0.2 | 2.0 | 2.4 | 2.7 | 1.7 | 9.2 | 2.69 | 1.1 | 0.72 | 0 | 0 | 0 | 0 | 4.6 | 59.65% | 100.00% | 79.82%
4 | a | 1 | tap water | none | 2 | 0.6 | 0.2 | 2.0 | 2.4 | 2.7 | 1.7 | 9.2 | 2.75 | 1.17 | 0.96 | 0.1 | 0 | 0.004 | 0 | 4.32 | 55.22% | 99.91% | 77.56%
10 | c | 1 | tap water + CaCl2 | none | 1 | 0.6 | 0.2 | 2.0 | 2.4 | 2.7 | 1.7 | 9.3 | 2.64 | 1.33 | 0.72 | 0.19 | 0 | 0.0003 | 0 | 4.37 | 54.10% | 99.99% | 77.05%
1 | a | 1 | tap water | none | 1 | 0.6 | 0.2 | 2.0 | 2.4 | 2.7 | 1.7 | 9.2 | 2.54 | 1.43 | 1.09 | 0.35 | 0 | 0 | 0 | 3.7 | 46.95% | 100.00% | 73.48%
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

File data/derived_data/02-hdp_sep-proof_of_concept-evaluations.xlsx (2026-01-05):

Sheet: evaluation
id | sep_sol_id | sep_sol | in_PS_g | in_PET_g | in_PVC_g | in_tot_g | float_right_g | float_PET_g | float_PVC_g | sink_PS_g | sink_right_g | purity_float | purity_sink | combined_purity
3 | c | dense sink-float | 2.4 | 2.7 | 1.7 | 6.8 | 2.39 | 0.08 | 0 | 0 | 4.2 | 96.76% | 100.00% | 98.38%
1 | a | swirling | 2.4 | 2.7 | 1.7 | 6.8 | 0.76 | 0.03 | 0 | 1.63 | 4.23 | 96.20% | 72.18% | 84.19%
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

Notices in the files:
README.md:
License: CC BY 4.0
